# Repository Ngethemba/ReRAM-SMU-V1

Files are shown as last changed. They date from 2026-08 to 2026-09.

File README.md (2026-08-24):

# ReRAM-SMU V1 — Precision Source Measure Unit

**Homemade precision SMU for low-voltage ReRAM / memristive device characterization and precision-electronics education.**

> ⚠️ **Project Stage: Phase 2 — Architecture & Candidate Component Verification — COMPLETE**
> No schematic, no PCB, no BOM has been validated. All architecture is provisional and requires simulation verification. This is an engineering instrument project, not a hobby circuit.

**Repository:** `https://github.com/Ngethemba/ReRAM-SMU-V1` — **PRIVATE**, branch `master`, 4 commits (`d5a6100`, `7b967de`, `3658117`, `57531ec`).

## What This Is

ReRAM-SMU V1 is a four-quadrant Source Measure Unit (SMU) targeting:

- Bipolar voltage source approx. **±5 V** (primary ReRAM region ±2 V), **±10 mA** sink/source
- Low-current measurement down to **several nA** (V1 useful floor), with six current ranges 100 nA – 10 mA
- Kelvin (4-wire) DUT interface: FORCE HI / SENSE HI / SENSE LO / FORCE LO
- Hardware current compliance, USB + SCPI-like control, Python-automated I–V sweeps

It is simultaneously an **educational platform** covering precision analog, DAC/ADC systems, four-quadrant operation, low-current design, compliance, Kelvin sensing, firmware, calibration, PCB layout, and automated characterization.

## Current Status

- **Phase:** `Phase 2 — Architecture & Candidate Component Verification — COMPLETE → Phase 3 ready`
- **Repository:** [`https://github.com/Ngethemba/ReRAM-SMU-V1`](https://github.com/Ngethemba/ReRAM-SMU-V1) (PRIVATE)
- **Dashboard:** [`STATUS.md`](STATUS.md)
- **Requirements:** [`REQUIREMENTS.md`](REQUIREMENTS.md) — confirmed / provisional / future separated
- **Risks & Decisions:** [`RISKS.md`](RISKS.md) · [`DECISIONS.md`](DECISIONS.md)
- **Open Questions:** [`OPEN_QUESTIONS.md`](OPEN_QUESTIONS.md)
- **Work Log:** [`docs/research/WORK_LOG.md`](docs/research/WORK_LOG.md)

No block is marked validated. All candidate components are `PROVISIONAL / REQUIRES VERIFICATION`.

## Repository Layout

```
ReRAM-SMU-V1/
├── README.md / PROJECT_CHARTER.md / REQUIREMENTS.md / ENGINEERING_RULES.md
├── ROADMAP.md / STATUS.md / DECISIONS.md / RISKS.md / OPEN_QUESTIONS.md / CHANGELOG.md / AGENTS.md
├── docs/            — architecture, research, calculations, calibration, safety, test, references
├── hardware/        — KiCad sources, symbols, footprints, mechanical, prototypes
├── simulation/      — SPICE, Python, results
├── firmware/        — MCU source, headers, tests, docs
├── software/        — instrument-control, gui, analysis, tests
├── bom/             — candidates / approved / sourcing
├── manufacturing/   — gerbers, assembly, release
├── measurements/    — raw / processed / calibration  (raw data is never deleted)
├── tools/           — scripts, setup
└── archive/         — superseded material
```

## Safety Statement

- **V1 has NO direct 230 V mains on the SMU PCB.** Development uses an external lab supply (nominal ±12 V analog rails).
- **Output defaults to DISABLED** on power-on, firmware reset, and fault. Never assume the output is safe.
- **First tests use dummy loads and precision resistors** — never a real ReRAM sample on a new revision.
- Prototype hardware must be tested with **current-limited bench supplies**.
- Exposed conductors and incorrect Kelvin wiring can damage the DUT, the SMU, and test equipment.
- Future higher-voltage revisions require a separate safety review — see [`docs/safety/`](docs/safety/).

## Engineering Philosophy (summary)

Primary datasheets override AI claims. Every critical decision needs documented justification and independent recalculation. Simulation is required before PCB but does not prove low-current performance. Resolution ≠ accuracy. Traceability is mandatory.

Full rules: [`ENGINEERING_RULES.md`](ENGINEERING_RULES.md) · Charter: [`PROJECT_CHARTER.md`](PROJECT_CHARTER.md)

## For AI Agents

Read `AGENTS.md` and the five mandatory files (`PROJECT_CHARTER.md`, `REQUIREMENTS.md`, `STATUS.md`, `DECISIONS.md`, `ENGINEERING_RULES.md`) before any engineering work. Never invent specs; cite primary datasheets.

## License / Provenance

All datasheet-derived statements must record manufacturer, part number, document title/revision, page/section, and source URL or local path under `docs/references/`.

---
*Initialized 2026-08-24 — Phase 0. No hardware has been designed or ordered.*

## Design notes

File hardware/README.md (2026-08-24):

# Hardware

KiCad sources are authoritative. Generated Gerbers are artifacts in `manufacturing/`.

- `kicad/` — schematics and PCB
- `symbols/` / `footprints/` — project-local libraries
- `mechanical/` — enclosure, mounting
- `prototypes/` — prototype notes, rework logs

No PCB manufactured until schematic/ERC/simulation/design reviews pass.

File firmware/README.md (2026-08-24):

# Firmware

STM32 (candidate: G431) firmware. Safe-state invariant: output disabled on boot/reset/fault.

- `src/` / `include/` — source
- `tests/` — host/unit tests
- `docs/` — firmware design notes

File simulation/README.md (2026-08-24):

# Simulation

- `spice/` — LTspice / ngspice sources (.asc, .cir, .lib)
- `python/` — system-level, Monte Carlo, noise budgeting scripts
- `results/` — plots and reports with date + tool version + models used

Simulation does not prove low-current / leakage / layout-dependent performance.

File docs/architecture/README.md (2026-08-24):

# Architecture

Authoritative block diagrams, power tree, signal chain, and grounding/isolation/guard strategy.

- `ARCHITECTURE.md` — system block diagram (added in Phase 2)
- Proposals here are **provisional** until a `DECISIONS.md` entry promotes them.

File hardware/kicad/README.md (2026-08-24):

# KiCad Project

Project files (`.kicad_pro`, `.kicad_sch`, `.kicad_pcb`) live here. Keep ERC/DRC clean; waivers documented in review record.

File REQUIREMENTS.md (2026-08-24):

# ReRAM-SMU V1 — Requirements

**Version:** 0.2.0 — Phase 1 verified  
**Date:** 2026-08-24  
**Status:** CONFIRMED / REVISED / PROVISIONAL / FUTURE per below. Provisional from v0.1.0 that is now supported has been promoted; promotions cite Phase 1 research.  
**Convention:** `REQ-<DOMAIN>-<NNN>` · Domains: SRC, MEAS, SAFE, DUT, SW, PWR, CAL, GEN

> **Rule:** Never silently convert a provisional target or future item into a confirmed requirement. Promotion requires a `DECISIONS.md` entry with evidence — this version's promotions are backed by DEC-007 through DEC-015 and Phase 1 research in `docs/research/` + `docs/calculations/`.

---

## How to Read This Document

- **CONFIRMED** — binding for V1 unless formally changed.
- **REVISED** — provisional target changed based on Phase 1 evidence (old → new shown).
- **PROVISIONAL** — still plausible but insufficient evidence; do not design to its limits without verification.
- **Future / V2+** — explicitly not V1; recorded to avoid scope creep.
- **REJECTED** — not justified for V1.

Each requirement lists ID, statement, rationale, verification method, status, and Phase 1 trace (`docs/research/` + `docs/calculations/`).

---

## 1. Source Capability — `REQ-SRC-*`

### REQ-SRC-001 — Bipolar Voltage Source Range (PROVISIONAL — verified as reasonable)

**Statement:** Nominal voltage source approximately **−5 V to +5 V** continuous, four-quadrant, source/sink.  
**Rationale:** Covers primary ±2 V ReRAM SET/RESET plus forming headroom (+2.4–5 V) without high-voltage/interlock complexity. ±10 V would not materially improve utility for low-voltage stacks.  
**Evidence:** `docs/research/RERAM_MEASUREMENT_REQUIREMENTS.md` §2/§5.1 (Vset +0.6–1.5 V on HfO2/TaOx/[C12mim], forming +2–+5 V); `COMMERCIAL_SMU_BENCHMARK.md` §4 (commercial lowest tier ±21 V; V1 ±5 V sits inside most accurate 2 V–20 V band).  
**Verification:** Sourcing into R + C loads across –5→+5 V; DMM vs FORCE/SENSE.  
**Status:** `PROVISIONAL — VERIFIED AS REASONABLE / REQUIRES MEASURED HEADROOM CHECK` — supported, not yet promoted to CONFIRMED pending power-stage headroom analysis (Phase 3).

### REQ-SRC-002 — Primary ReRAM Operating Region (PROVISIONAL — well-supported)

**Statement:** Primary region approximately **−2 V to +2 V** must be within linear, low-noise operating envelope with best accuracy.  
**Rationale:** >80% of reported SET/RESET on dozens of filamentary stacks (HfO2, TaOx, TiO2, Al2O3, GCMO, nanowire, polymer) falls here. Read bias 0.1–0.5 V also inside region.  
**Evidence:** RERAM §2 table (Vset +0.6–1.5 V, Vreset –0.7––1.5 V), 0.01–0.05 V step / 50–100 ms dwell literature.  
**Verification:** Linearity and noise characterization in ±2 V window.  
**Status:** `PROVISIONAL — WELL-SUPPORTED` — expected to be CONFIRMED at Phase 3 after source-stage simulated.

### REQ-SRC-003 — Bipolar Operation (Confirmed)

**Statement:** System shall source and measure both positive and negative voltages and currents.  
**Rationale:** ReRAM bipolar switching; four-quadrant I–V required (0→+Vmax→0→–Vmax→0).  
**Evidence:** RERAM UC-1/2 (bipolar dominates), PHASE1 §3.  
**Verification:** Bipolar sweep test.  
**Status:** `CONFIRMED`

### REQ-SRC-004 — Source and Sink Capability (Confirmed)

**Statement:** Output stage shall source and sink current (active load).  
**Rationale:** Memristor/LRS can drive current back; SMU must absorb without quadrant-switch glitch.  
**Evidence:** `docs/research/SMU_ARCHITECTURE_SURVEY.md` §0 4-quadrant, `COMPLIANCE_RESEARCH.md` (sink needed for NDR).  
**Verification:** Load-step and quadrant test.  
**Status:** `CONFIRMED`

### REQ-SRC-005 — Four-Quadrant Architecture (CONFIRMED — promoted from PROVISIONAL-preferred)

**Statement:** Architecture shall be four-quadrant (source + sink, both polarities) — now mandatory for V1.  
**Rationale:** Phase 1 synthesis (all agents agree) shows ReRAM requires Q1 +V/+I, Q2 +V/–I sink, Q3 –V/–I, Q4 –V/+I; source/sink voltage-only is insufficient; power is modest (~50 mW @±5 V·±10 mA) but sink accuracy (4–8× offset penalty on commercial SMUs) must be characterized.  
**Evidence:** PHASE1 §9, `SMU_ARCHITECTURE_SURVEY.md`, RERAM §2/§5.5.  
**Verification:** Architecture review + quadrant-transition scope capture (sink vs source error separate).  
**Status:** `CONFIRMED` — DEC-007 (Phase 1).

### REQ-SRC-006 — Maximum DUT Current (PROVISIONAL — verified)

**Statement:** Target maximum DUT current approximately **±10 mA** continuous (DC; pulse forming not in V1).  
**Rationale:** HfO2/TiO2 standard Icc 100 µA–1 mA, RESET 0.2–3 mA, Al2O3 forming 1–15 mA edge — 10 mA gives 10× margin over typical Icc without pulse/high-power. 100 mA not justified (no low-voltage evidence) and would add SOA/thermal burden.  
**Evidence:** RERAM §2 (10 µA–1 mA most common Icc; 10 mA max with headroom) + COMMERCIAL §4 (V1 ±10 mA is lowest commercial max-current tier, cheapest precision tier).  
**Verification:** Current-drive test into low-impedance load at compliance.  
**Status:** `PROVISIONAL — VERIFIED AS REASONABLE` — confirmed against evidence; promotion pending output-stage headroom: REQ-PWR-003 analysis.

### REQ-SRC-007 — Output Enable / Disable (Confirmed)

**Statement:** Firmware and hardware shall provide explicit output enable/disable with safe default.  
**Verification:** Power-cycle and fault tests (see REQ-SAFE).  
**Status:** `CONFIRMED`

---

## 2. Measurement Capability — `REQ-MEAS-*`

### REQ-MEAS-001 — Current Ranges (CONFIRMED — promoted from PROVISIONAL)

**Statement:** V1 current measurement ranges: **10 mA, 1 mA, 100 µA, 10 µA, 1 µA, 100 nA** (6 log ranges, autoranging). **10 nA and 100 mA are explicitly not V1** (see REQ-MEAS-006).  
**Rationale:** Logarithmic cover from forming (mA) to HRS leakage (hundreds nA): CMOS on-chip platform 20 nA–2 mA (5 decades) + GCMO HRS 10⁷–10⁸ Ω needs nA; R=10 Ω–1 MΩ at 100 mV FS gives Johnson <1% FS @10 Hz down to 100 nA (BURDEN table).  
**Evidence:** RERAM §2 (Icc 10 µA–1 mA → LRS mA, HRS nA), `LOW_CURRENT_MEASUREMENT.md` §3 + `docs/calculations/BURDEN_VOLTAGE_ANALYSIS.md` (R 10–1 MΩ, 1.0 mW→10 nW, TC 0.025%).  
**Verification:** Shunt + amplifier + ADC chain analysis; per-range calibration vs precision resistor.  
**Status:** `CONFIRMED` — DEC-008.

### REQ-MEAS-002 — V1 Lower Measurement Region (CONFIRMED as quantified — was PROVISIONAL “several nA”)

**Statement:** Target V1 useful lower region: **several nA** — quantified as **detection 3σ ≈ 1.5–6 pA, quantitative 10σ ≈ 5–20 pA on 100 nA range (1 MΩ, 10 Hz BW, Johnson 0.41 pA rms), practical quantitative MUC ≈ 1 nA (≈10% of 100 nA range) with averaging/shielding, leakage-corrected.** Resolution (e.g., 24-bit LSB ≈6 fA) is reported separately and is not the floor.  
**Rationale:** Mn3O4 selector OFF 4 nA, HRS 10 nA–0.4 µA range; pA is V2 with guard-driven triax/electrometer (REQ-MEAS-006). “Several nA” was not an acceptable final requirement — now measurable per above.  
**Evidence:** LOW_CURRENT §1.1/3.1 (100 nA guard-required, leakage-limited), NOISE_BUDGET framework (Johnson 0.41 pA @10 Hz/1 MΩ), PHASE1 §6.  
**Verification:** Noise-floor time series (shorted input, NPLC=1, Allan deviation) + system leakage open-input test (100 s); report mean ±σ at 100 nA range.  
**Status:** `CONFIRMED` (quantified) — DEC-009.

### REQ-MEAS-003 — Voltage Measurement (Confirmed, extent provisional — accuracy targets added as research)

**Statement:** System shall measure DUT voltage (Force and Sense) with accuracy adequate for I–V characterization. Phase 1 research accuracy targets (not yet CONFIRMED): source/measure V ±(0.02% reading + 0.01% FS + 2 ppm/°C·ΔT), e.g., ±0.5 mV @1 V, ±2 mV @2 V; cal residual <½ spec; NPLC 1–10 trade.  
**Evidence:** PHASE1 §7 (targets are 2–5× looser than Keithley 0.012% intentionally), UNCERTAINTY framework.  
**Verification:** Comparison against calibrated DMM (e.g., 34465A) at –2,–1,0,+1,+2 V.  
**Status:** `CONFIRMED (existence) / PROVISIONAL (numbers)` — numbers are research targets pending Phase 3 simulation + measurement.

### REQ-MEAS-004 — Autoranging (Confirmed)

**Statement:** System shall support autoranging across current ranges with documented hysteresis/dwell (≥2 samples post-trip, hold range to avoid chatter at HRS↔LRS transition) to avoid chatter. Must respect `I_compliance ≤ I_range` invariant (range compliance).  
**Evidence:** RERAM §4 WF-1 autorange note + COMPLIANCE §6 (range compliance, holdoff for C·dV/dt).  
**Verification:** Automated sweep crossing range boundaries; chatter count.  
**Status:** `CONFIRMED`

### REQ-MEAS-005 — Resolution ≠ Accuracy (Confirmed, informational)

**Statement:** Documentation and software shall never conflate ADC/DAC resolution with system accuracy; both shall be reported separately per MEASUREMENT_ENVELOPE table; LSB (e.g., 6 fA on 100 nA/24-bit) is not accuracy.  
**Evidence:** LOW_CURRENT §1.1 table (LSB 5.96 fA vs Johnson 0.41 pA), REQ-CAL-003.  
**Verification:** Review of docs + software display.  
**Status:** `CONFIRMED`

### REQ-MEAS-006 — Future Low-Current Extension (Future / V2)

**Statement:** Future revisions may target 10 nA, pA, and electrometer-class measurements (10 MΩ shunt, guard-driven triax, Teflon standoffs, ADA4530-1, enclosure). Not required for V1; 10 nA is explicitly FUTURE and needs electrometer daughter-card.  
**Evidence:** LOW_CURRENT §3.1 V2 analysis (10 GΩ leak →10 pA @100 mV, 5 nA @5 V →100% FS).  
**Status:** `FUTURE / NOT V1`

### REQ-MEAS-007 — Voltage Source Accuracy (NEW — provisional research target)

**Statement:** Provisional source accuracy target for V1 (post-cal, 25±3 °C, k=2 expanded where noted): at –2,–1,0,+1,+2 V — research aim ±(0.02% reading + 0.01% FS + 2 ppm/°C·ΔT + drift); bias at 0 V within ±200 µV. Promoted only after Phase 3 simulation + DMM comparison.  
**Verification:** DMM sweep tie against calibrated reference.  
**Status:** `PROVISIONAL / RESEARCH TARGET`

### REQ-MEAS-008 — Current Measurement Accuracy (NEW — provisional research target)

**Statement:** Provisional current measurement accuracy (research, k=2): 10 mA ±(0.03%+10 µA), 1 mA ±(0.03%+1 µA), 100 µA ±(0.05%+200 nA), 10 µA ±(0.08%+20 nA), 1 µA ±(0.1%+5 nA), 100 nA (@50 nA) ±(0.3%+60 pA) ≈1σ 30 pA (dominant: shunt 0.1%/√3 + Ileak 5 pA/√3 + Johnson 0.41 pA).  
**Verification:** Precision resistor V/I tie per range; leakage-corrected.  
**Status:** `PROVISIONAL / RESEARCH TARGET`

---

## 3. Protection and Control — `REQ-SAFE-*`

### REQ-SAFE-001 — Hardware Current Compliance (Confirmed — revised per DEC-024)

**Statement:** A **hardware** current compliance / protection loop shall limit DUT current independent of firmware, per compliance triad: compliance regulation (flat CC, flagged, SMU stays in circuit) distinct from range compliance and SOA trip (crowbar). Icc programmable as value within range (not decade-locked). For LT1970A-based limiters the minimum programmable compliance is limited by the 4 mV VSENSE floor (~4% of FS at 100 mV FS, ~16% at 25 mV FS) and the Vc<60 mV nonlinear region — see DEC-024 and `docs/research/PHASE2_INDEPENDENT_REVIEW_CORRECTIONS.md` IR-01. A `0.1%·I_range` target applies only to the precision external CC-loop (Source Candidate C) and is otherwise satisfied via **compliance-aware automatic range coercion** (requested Icomp selects an achievable hardware range). The compliance reference shall be DAC-driven per segment (no hard-wired trimpot), with per-polarity source/sink control.  
**Verification:** Fault injection: short + step load; scope I overshoot & flag timing. Targets (research): regulation settle <50 µs to Icc, trip <5 µs, overshoot <1% (resistive) / <5% into 1 nF with soft-start, SOA hyperbola |V·I|≤50–60 mW DC, flag latency ≤1 NPLC. Hardware must function with MCU halted.  
**Status:** `CONFIRMED (revised 2026-08-24, DEC-024 — original 0.1% Keithley rule retained only for precision-loop tier)`

### REQ-SAFE-002 — Software Current Limits (Confirmed)

**Statement:** Firmware/software shall enforce configurable current limits in addition to hardware compliance (secondary polygon: isw_limit, v_limit, power_limit, pre-check gate, soft-start ramp).  
**Verification:** Software limit trip test.  
**Status:** `CONFIRMED`

### REQ-SAFE-003 — Safe Power-On State (Confirmed)

**Statement:** On power-on, brown-out, firmware reset, or watchdog reset, output shall default to **disabled / high-impedance safe state** with compliance reference defaulting to minimum I-range.  
**Verification:** Power-cycle + reset tests with output monitored.  
**Status:** `CONFIRMED`

### REQ-SAFE-004 — Output Disabled on Firmware Failure (Confirmed)

**Statement:** Firmware fault, hang, or watchdog timeout shall disable output.  
**Verification:** Watchdog timeout test.  
**Status:** `CONFIRMED`

### REQ-SAFE-005 — Bipolar I–V Sweeps (Confirmed)

**Statement:** System shall execute bipolar I–V sweeps (programmed voltage steps, measured current) with built-in preset `0→+Vmax→0→–Vmax→0`, step 1–50 mV (default 10 mV), dwell 10 ms–2 s (default 50–100 ms, interstep 10 ms), ≥200 pts/loop, compliance-hit handling (flag+hold range), autorange, abort on interlock/OT/watchdog.  
**Verification:** Sweep automation test.  
**Status:** `CONFIRMED`

### REQ-SAFE-006 — Temperature Monitoring (Confirmed)

**Statement:** System shall monitor temperature of critical subsections (output stage, shunts, reference) — 1 per zone (NTC or digital e.g., TMP117); logging is sufficient for V1 (compensation is V1.x/V2). Assumed operating 15–30 °C lab.  
**Verification:** Thermal test + over-temperature response.  
**Status:** `CONFIRMED`

### REQ-SAFE-007 — Fault Monitoring (Confirmed)

**Statement:** System shall detect and report faults (over-current, over-temperature, compliance active distinct from fault, supply faults, reverse energy). Every sample logs `range_state`, `compliance_flag/type`, `Icomp/Vcomp`, `I_range/V_range`.  
**Verification:** Fault-injection matrix.  
**Status:** `CONFIRMED`

### REQ-SAFE-008 — Watchdog / Error Handling (Confirmed)

**Statement:** Firmware shall include watchdog and structured error handling that forces safe state on failure.  
**Verification:** Watchdog + error-path tests.  
**Status:** `CONFIRMED`

---

## 4. DUT Interface — `REQ-DUT-*`

### REQ-DUT-001 — Kelvin / 4-Wire Support (Confirmed — addendum per IR-02/03)

**Statement:** DUT interface shall support **FORCE HI, SENSE HI, SENSE LO, FORCE LO** and Kelvin/4-wire measurement with remote sense **>10 GΩ achieved via a high-Z buffer before any attenuation/dividing stage (IR-02)**, 5 V force–sense drop, 1 MΩ lead tolerance, open-sense detection via switched disconnect (≥10 GΩ effective or disconnected during measurement — IR-03), 2-write/4-wire mode.  
**Verification:** 2-wire vs 4-wire comparison on 1 kΩ and 10 Ω dummy (LRS); max-drop test; DUT loading sweep 1 MΩ/10 MΩ/100 MΩ/1 GΩ (IR-02).  
**Status:** `CONFIRMED (addendum 2026-08-24 — buffer-first, switched open-sense)`

### REQ-DUT-002 — Connector Strategy (Provisional — deferrable to Phase 2)

**Statement:** V1 connector type TBD (banana, BNC, terminal block, or Kelvin clip). Must support shielded/leakage-conscious wiring path for future guard (guard-ring copper, exposed no-mask, inner guard plane, C0G-only on high-Z path) without claiming guard performance.  
**Verification:** Architecture decision in Phase 2 per LOW_CURRENT §4 checklist.  
**Status:** `PROVISIONAL / REQUIRES VERIFICATION` — updated to note guard-ring provision even though triax is deferred.

### REQ-DUT-003 — Triax / Driven Guard / Electrometer Front-End (Future)

**Statement:** Triax connectors, driven guard, and electrometer front-end are **future revisions**, not V1. Explicitly includes 10 nA range electrometer daughter-card. V1 acknowledges this as the path to 10⁻¹⁴ Ω guard.  
**Status:** `FUTURE / NOT V1`

---

## 5. Computer Interface — `REQ-SW-*`

### REQ-SW-001 — USB Interface (Confirmed)

**Statement:** Instrument shall be computer-controlled via **USB** (USB-TMC or USB-CDC class; GPIB/LXI not required).  
**Verification:** USB enumeration + command round-trip.  
**Status:** `CONFIRMED`

### REQ-SW-002 — SCPI-like Command Interface (Confirmed)

**Statement:** Firmware shall expose an **SCPI-like** command interface (subset: SOURCE:VOLT, SOURCE:CURR:LIM, MEAS:VOLT?, MEAS:CURR?, OUTPUT:ENABLE, sweeps; linear dual sweep + list/custom as minimum). Full SCPI compliance not required.  
**Verification:** Command-set tests against spec in `docs/`.  
**Status:** `CONFIRMED`

### REQ-SW-003 — Python Control (Confirmed)

**Statement:** A **Python** control library/client shall drive the instrument (sweeps, config, readout).  
**Verification:** Python integration tests.  
**Status:** `CONFIRMED`

### REQ-SW-004 — Automated Sweep Execution (Confirmed)

**Statement:** Software shall support automated sweep execution (configurable start/stop/step/delay/dwell, bidirectional, holdoff, compliance-flag handling, timestamped buffer).  
**Verification:** Sweep test with logged data.  
**Status:** `CONFIRMED`

### REQ-SW-005 — Data Export (Confirmed)

**Statement:** Software shall export data as **CSV and raw data** with metadata (timestamp, range, compliance_flag/type, Icomp/Vcomp, range_state, temperature).  
**Verification:** Export format test; raw data preservation check.  
**Status:** `CONFIRMED`

---

## 6. Power Architecture — `REQ-PWR-*`

### REQ-PWR-001 — No Direct Mains on SMU PCB (Confirmed)

**Statement:** V1 SMU PCB shall have **no direct 230 V mains circuitry**.  
**Verification:** Schematic/PCB review checklist.  
**Status:** `CONFIRMED`

### REQ-PWR-002 — External Lab Supply for Development (Confirmed)

**Statement:** Development and bring-up shall use an **external laboratory supply**.  
**Verification:** Bring-up procedure.  
**Status:** `CONFIRMED`

### REQ-PWR-003 — Nominal Analog Rails (PROVISIONAL — still provisional)

**Statement:** Nominal analog rails approximately **±12 V**, subject to output-stage headroom analysis (must supply ±5 V + 25–100 mV burden + dropout + SOA). AD5764, if selected, requires **±11.4 V minimum** (see IR-07) — ±10 V LDO rails are **not** AD5764-compatible; V1 power-tree Options A/B/C defined in `POWER_TREE.md`.  
**Verification:** Headroom + dropout analysis (regulators, LT1970A or alternative; AD5764 ±11.4 V spec).  
**Status:** `PROVISIONAL / REQUIRES VERIFICATION` — compatible with LT1970A on raw ±12 V (Option A).

### REQ-PWR-004 — Analog / Digital Supply Treatment (Confirmed, extent provisional)

**Statement:** Design shall provide **separate analog/digital supply treatment** as needed (regulation, filtering, star-point/partition, **one continuous reference plane with no etched AGND/DGND split — separation by placement, local return-current control, routing discipline, and decoupling (IR-13)**, LC π-filter, PSRR ≥80 dB at ripple, NPLC mains nulling).  
**Verification:** Power architecture review + noise PSD with/without USB.  
**Status:** `CONFIRMED (principle) / PROVISIONAL (implementation) — wording corrected per IR-13`

---

## 7. Calibration & Quality — `REQ-CAL-*`

### REQ-CAL-001 — Calibration Procedure (Confirmed)

**Statement:** V1 shall have a documented calibration procedure with traceability, distinguishing adjustment vs verification vs calibration vs traceable calibration (GUM). References: calibrated 6½-digit DMM, class 0.01% precision resistors (1 kΩ–1 MΩ), 2.5 V reference cert.  
**Verification:** `docs/calibration/` + calibration report.  
**Status:** `CONFIRMED`

### REQ-CAL-002 — Verification on Dummy Loads First (Confirmed)

**Statement:** First hardware tests shall use **dummy loads and precision resistors** (1 kΩ,10 kΩ,100 kΩ,1 MΩ linear I–V + compliance trip + Kelvin delta + autorange chatter); no ReRAM sample as first DUT; DUT type logged in every measurement file.  
**Verification:** Bring-up log + risk verifications per RERAM §5.5.  
**Status:** `CONFIRMED`

### REQ-CAL-003 — Uncertainty Budget (Confirmed)

**Statement:** V1 shall publish a measurement uncertainty discussion (not just resolution), per `docs/calculations/UNCERTAINTY_BUDGET_FRAMEWORK.md` (GUM JCGM 100): categories S1–S10, M1–M10, V1–V4, C1–C7; RSS `u_c=√(Σu_i²)`, rectangular `a/√3`, expanded `U=k·u_c (k=2)`; type A from measured σ; Monte Carlo Supplement 1 teaser.  
**Verification:** Calibration/verification report vs external DMM.  
**Status:** `CONFIRMED` — framework now exists.

---

## 8. General / Process — `REQ-GEN-*`

### REQ-GEN-001 — Simulation Before PCB (Confirmed)

**Statement:** Simulation is required before PCB implementation where practical (now with hybrid workflow: ngspice primary, LTspice secondary).  
**Verification:** Simulation results in `simulation/results/` with date/tool-version/models.  
**Status:** `CONFIRMED`

### REQ-GEN-002 — Reviews Before Manufacturing (Confirmed)

**Statement:** No PCB manufactured until schematic review, ERC, simulation review, and design review are complete (guard-ring checklist included).  
**Verification:** Review checklists in `docs/`.  
**Status:** `CONFIRMED`

### REQ-GEN-003 — Traceability (Confirmed)

**Statement:** Design decisions remain traceable (requirements → decisions → evidence), now via `docs/architecture/REQUIREMENTS_TRACEABILITY.md` mapping each REQ to evidence.  
**Verification:** `DECISIONS.md` coverage check.  
**Status:** `CONFIRMED`

---

## Summary Counts (v0.2.0)

| Category | Confirmed | Provisional | Future | Notes vs v0.1.0 |
|---|:---:|:---:|:---:|---|
| SRC | 4 (was 2) | 3 (was 4) | 0 | REQ-SRC-005 promoted |
| MEAS | 6 (was 3) | 2 (was 2) | 1 | REQ-MEAS-001/002 promoted, 007/008 added provisional |
| SAFE | 8 | 0 | 0 | unchanged count, REQ-SAFE-001/005 enriched |
| DUT | 1 | 1 | 1 | unchanged |
| SW | 5 | 0 | 0 | unchanged |
| PWR | 2 | 1(+1 partial) | 0 | unchanged |
| CAL/GEN | 6 | 0 | 0 | unchanged |

**Total confirmed V1 requirements:** 31 (was 27) · **Provisional targets:** 7 (was 8) + 2 new research provisional = 9 · **Future:** 3

---

## Candidate Components (Informational — Not Requirements)

Unchanged — still **PROVISIONAL / REQUIRES VERIFICATION**: STM32G431 family, AD5686R, ADA4522-2, LT1970A, ADS1262, LT1763, ADR4525-class, shunts + relay range switching. No component promoted in Phase 1. Do not propagate specs from memory.

---

## Change Log (v0.1.0 → v0.2.0)

- DEC-007: REQ-SRC-005 four-quadrant promoted to CONFIRMED.
- DEC-008: REQ-MEAS-001 six ranges promoted to CONFIRMED; 100 mA rejected, 10 nA FUTURE.
- DEC-009: REQ-MEAS-002 several-nA quantified (detection 3σ ~1.5–6 pA, quantitative 10σ ~5–20 pA, practical 1 nA) and CONFIRMED.
- REQ-SRC-001/002/006 wording unchanged but status updated to PROVISIONAL-verified with evidence citations.
- NEW REQ-MEAS-007/008 accuracy research targets added as PROVISIONAL.
- REQ-SAFE-001/005 enriched with compliance triad and sweep parametric table (research targets for timing).
- REQ-DUT-002 updated to require guard-ring provision despite triax deferral.
- REQ-PWR-004 enriched with NPLC mains nulling.
- REQ-CAL-003 now references uncertainty framework.
- Traceability to Phase 1 research added per REQ.

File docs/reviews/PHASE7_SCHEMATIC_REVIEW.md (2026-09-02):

# Phase 7 Schematic Review — ReRAM-SMU V1

**Project:** ReRAM-SMU V1 — Phase 7 Schematic Capture (Hierarchical)
**Date:** 2026-08-25
**HEAD:** `3899852` → this review (`hardware/kicad/ReRAM-SMU-V1/`)
**Status:** `PARTIAL — HIERARCHICAL SKELETON WITH PROVISIONS, ERC WITH WAIVERS`
**Artifacts:** `hardware/kicad/ReRAM-SMU-V1/` (root + 9 sheets), `hardware/kicad/erc.json`, `hardware/kicad/netlist.xml`, this file

---

## 1. Roadmap Normalization

Original Roadmap Phases 4–6 scope (Current Measurement, Hardware Compliance, Integrated Simulation) was **absorbed into Expanded Phase 3** as documented in `simulation/results/phase3/` (Tests A-O, Gates 1-6) and corrective reviews `PHASE3_INDEPENDENT_REVIEW_CORRECTIONS.md`, `PHASE3_CORRECTIVE_RESULTS.md`, `R5_1_TOPOLOGY_CORRECT_VENDOR_RESULTS.md` (vendor LT1970.sub with corrected low-side shared shunt + differential Kelvin). All Phase 4–6 exit criteria were satisfied within Expanded Phase 3:

- Phase 4 (Current Measurement): shunts 2.5Ω–1MΩ + ADA4522/OPA140 + ADS1262 (primary) + noise/leakage — consolidated 2026-08-25
- Phase 5 (Hardware Compliance): LT1970 continuous CC + TLV3501 emergency trip + FILTER DNP/open + R_iso 33/47Ω — consolidated
- Phase 6 (Integrated): end-to-end co-sim, power tree, one continuous plane grounding, guard — consolidated

Phases 4–6 marked `COMPLETED AS PART OF EXPANDED PHASE 3 / CONSOLIDATED` in `ROADMAP.md` (commit `3899852`). **Phase 7 — Schematic Capture** is now the canonical schematic phase.

---

## 2. Schematic Structure

**Location:** `hardware/kicad/ReRAM-SMU-V1/`

```
hardware/kicad/ReRAM-SMU-V1/
├── ReRAM-SMU-V1.kicad_pro
├── ReRAM-SMU-V1.kicad_sch (root with 9 hierarchical sheets)
└── sheets/
    ├── 01_POWER.kicad_sch
    ├── 02_DAC_SOURCE_COMMAND.kicad_sch
    ├── 03_OUTPUT_STAGE.kicad_sch
    ├── 04_KELVIN_SENSE.kicad_sch
    ├── 05_CURRENT_RANGES.kicad_sch
    ├── 06_CURRENT_FRONTEND_ADC.kicad_sch
    ├── 07_COMPLIANCE_TRIP.kicad_sch
    ├── 08_MCU_USB_CONTROL.kicad_sch
    └── 09_DUT_CONNECTOR_GUARD.kicad_sch
```

| Sheet | Title | Key Content (Phase 7) |
|---|---|---|
| 01 | 01_POWER | ±12V EXT input, polyfuse, LT3045/LT1763 +5V_A/+3V3, LTC6655-5.0 (AD5764) + LTC6655-2.5 (ADC) refs, POR supervisor, decoupling, TP_POWER |
| 02 | 02_DAC_SOURCE_COMMAND | AD5764 (LQFP-32, 5V ref 20V span half-codes 305µV), LTC6655-5.0, **slew RC 1k + 1nF DNP/PROTOTYPE-TUNE** (R5.1 44% 0.1V risk mitigation), VSET conditioning, TP VREF_5V/DAC_OUT/VSET |
| 03 | 03_OUTPUT_STAGE | LT1970A TSSOP-20 ±12V, VCSRC/VCSNK, ENABLE, **R_iso 33Ω DNP / 47Ω PRIMARY selectable** (not parallel), **C_FILTER DNP/open baseline** with optional 1nF–100nF footprint (LOOP_TUNE), ISRC/ISNK 10k pull-ups to 3.3V, TP LT1970 OUT/FORCE_HI |
| 04 | 04_KELVIN_SENSE | OPA140 SENSE_HI/SENSE_LO buffers (>10GΩ, 5pF), diff amp finite BW 10MHz, **reed relay <1pA** open-sense (not ADG1419), guard keepout provision, TP SENSE_HI_BUF/SENSE_LO_BUF/DIFF |
| 05 | 05_CURRENT_RANGES | **Shared low-side 2.5Ω/25Ω/500Ω/5kΩ/100kΩ/1MΩ** (25/50/100mV FS), Kelvin sense points, break-before-make reed relays, safe default 1MΩ (de-energized), TP each shunt |
| 06 | 06_CURRENT_FRONTEND_ADC | ADA4522 (25/50mV) + OPA140 JFET (100k/1M) hybrid, **ADS1262 PRIMARY** (QFP-28, internal PGA 1-32, SINC4, midscale 2.5V), AD7175 alternate DNP, anti-alias RC, LTC6655-2.5 ref, TP ADC_IN_P/N |
| 07 | 07_COMPLIANCE_TRIP | LT1970 continuous CC via shared shunt (precision) + **TLV3501 emergency supervisor ONLY** (6.5mV, SOT-23-6, loose 120-150% threshold), separate, ISRC/ISNK pull-ups |
| 08 | 08_MCU_USB_CONTROL | STM32G474 LQFP-64, USB-C, relay drivers, watchdog, supervisor, status LEDs, **OUTPUT_ENABLE hardware-safe default (pull-down + supervisor, not firmware)**, TP ENABLE |
| 09 | 09_DUT_CONNECTOR_GUARD | 4-wire Kelvin connector (FORCE_HI/LO + SENSE_HI/LO), shield/chassis, **no driven guard stuffed** (keepout + optional footprint), ESD low-leak (0.5–2pF), TP FORCE/SENSE |

**Stale statements cleaned before capture:**
- FILTER baseline is **DNP/open**, optional 1nF–100nF per 1970afc — not active 220pF (previous 220p outside range, now DNP)
- Grounding is **one continuous reference plane, no etched AGND/DGND split or physical bridge** — per `GROUNDING_AND_RETURN_PATHS.md` corrected wording (placement/return-current/decoupling, not split)
- Previous high-side LT1970 vendor proxy (R5) marked **HISTORICAL / PROXY — NOT SELECTED TOPOLOGY VALIDATION** — authoritative is R5.1 low-side shared shunt + differential Kelvin
- R5.1 selected topology (OUT→R_iso→DUT→shared shunt, differential Vdiff servo, finite-bandwidth OPA140 pole, R_iso 47Ω sweet spot) is authoritative

---

## 3. Critical Architecture

### Source
- AD5764 @5V ref (LTC6655-5.0) ±10V span, half-codes for ±5V (305µV LSB, 3.0% of 10mV step, ±1LSB guaranteed at 5V), supply ±11.4–16.5V via raw ±12V (0.6V margin). AD5686R→×2 fallback DNP. Slew RC provision 1k+1nF DNP at VSET.

### Kelvin
- **Vdut = SENSE_HI − SENSE_LO** servoed to VSET, not FORCE_HI vs GND. OPA140 buffers (10pA max, 0.8fA noise) → diff amp (10MHz pole) → LT1970 -IN. Previous ideal VCVS replaced with realizable 3-op-amp diff. Reed <1pA open-sense, latch OFF, no ADG1419 in precision path.

### Current Ranges
- Shared low-side: 10mA 2.5Ω/25mV, 1mA 25Ω/25mV, 100µA 500Ω/50mV, 10µA 5kΩ/50mV, 1µA 100kΩ/100mV, 100nA 1MΩ/100mV (SHUNT_RANGE_TRADEOFF §2.4 D). Kelvin across shunts, LT1970 SENSE+→FORCE_LO, SENSE-→GND. BBM hardware+firmware: freeze/disable → break old → wait 5ms → make new → settle 10ms → zero → resume (23.5ms seq, per Test K).

### ADC
- **ADS1262 PRIMARY** (internal PGA 1-32, Vref/PGA limit 78mV@32, SINC4 20SPS single-cycle 50ms, 130dB notch). Requires only small 3.13× pre-gain for 25mV (vs 100× external for AD7175). AD7175 alternate DNP (needs external 100/50/25×). Midscale 2.5V, input RC, buffer, reference LTC6655-2.5.

### DAC
- LTC6655-5.0 5V (0.8ppm, 0.775µV p-p) for AD5764 REFAB/REFCD (spec condition), REF 5V ±1% for ±1LSB. ±5V uses half codes 16384–49151, document code-range consequence.

### Compliance / Protection
- Continuous: LT1970 VC/10 threshold via shared shunt (precise, 1% separate ISRC/ISNK, 4µs takeover). Emergency: TLV3501 loose supervisor 120–150% range-dependent (150%@1mA,130%@10µA,120%@100nA), not precision, separate latch/disable. ISRC/ISNK **pull-ups 10k to 3.3V** (R5.1 proven: Source Isrc 0.03V low/Isnk 3.3V, Sink opposite), not pull-downs.

### Power
- External ±12V bench (no mains on PCB) → analog ±12V_A (LT1970/AD5764), +5V_A via LT3045/LT1763 + LC π, +3V3 via TLV1117, por supervisor 10k pulldown + 200ms POR (Test L). One continuous plane, star via placement/decoupling.

---

## 4. ERC — Headless Verification 2026-09-02 (kicad-cli 9.0.8, ca7eac3 + cae70ef)

**Tool:** `kicad-cli sch erc --severity-error --format json` (headless 9.0.8) + `kicad-cli sch erc --severity-all` (WSL Ubuntu 26.04, kicad 9.0.8+dfsg-1)

**Outputs:** `hardware/kicad/erc.json` (124 errors headless), `hardware/kicad/netlist.xml` (kicadsexpr, 26 nets), `hardware/kicad/bom.csv` (119 refs), `hardware/kicad/erc_*_yolo.json` (yolo baseline), `erc_audit_lite.json`

**Headless ERC 124 errors breakdown (ca7eac3, was 128→124 via zero-length + annotate; 219 skeleton waived baseline superseded):**

| Check | Count | Evidence | Status / Path to 0 |
|---|---|---|---|
| pin_not_connected | 86 | ERC JSON pin_not_connected at TP, NC pins (AD5764 27/29, LT1970 10/11/18, OPA NC), DAC/OPA unconnected inputs | Detailed capture: wire TP to net, add no_connect for NC, connect DAC/OPA remaining pins |
| wire_dangling | 26 →22 (26 at 09e9bcd, 22-26 at ca7eac3 after 7×0 mm cleanup) | Root tiny wires 0.05–0.14 mm near (10,10) + 5V/GND stubs in 01/02/03 | Delete root dangling wires (ca7eac3 removed 4), wire 5V/GND stubs to PWR_FLAG/net |
| power_pin_not_driven | 10 | OPA V+/V-, LT1970 VEE/VCC without PWR_FLAG in 05/06 before 2c78781 fix (now 10 residual) | Add PWR_FLAG for OPA/LT1970 power pins (05/06 fixed, residual in 01/02/03 stubs) |
| other (endpoint_off_grid, lib_symbol_mismatch, footprint_link_issues remnants) | 2 | 2 remaining off-grid/footprint after grid snap 1.27 mm | Snap to 0.254 mm grid, curate library symbols (G431, AD5764, ADS1262) |
| **Total errors** | **124** | `kicad-cli sch erc --severity-error` JSON | **Pending detailed capture to 0** |
| warnings | 316 | severity-all total 440 (124 err +316 warn) | Warnings tracked separately |
| nan- nets | 26 | `erc_audit_lite.json` nan- prefix nets | Audit notes 26 nan- nets are valid global label nets, not floating |

**Per-sheet ERC (severity-error, from yolo 2026-09-01, updated ca7eac3):**

| Sheet | Errors | Notes |
|---|---|---|
| / (root) | 26 wire_dangling | Tiny wires at origin, 4 removed ca7eac3 → ~22 |
| /01_POWER/ | 25 | Power stubs, PWR_FLAG added 2c78781, residual 10 power_pin |
| /02_DAC_SOURCE_COMMAND/ | 31 | AD5764 NC 27/29, VSET slew RC DNP, pin-tip wiring now netlist-merged (a553152) |
| /03_OUTPUT_STAGE/ | 27 | LT1970 NC 10/11/18, ISRC/ISNK pull-ups 10k→3V3 verified, R_iso 47 PRIMARY |
| /04_KELVIN_SENSE/ | 13 | OPA140 buffers, diff LT5400 provisional, reed <1pA, guard DNP |
| /05_CURRENT_RANGES/ | 0 (was 0 after PWR_FLAG fix) | 6 shunts shared low-side 2.5Ω–1MΩ, relay coil tip wired (a553152) |
| /06_CURRENT_FRONTEND_ADC/ | 0 | ADS1262 PGA 32, OPA140 hybrid, pin-tip wired |
| /07_COMPLIANCE_TRIP/ | 0 | TLV3501 supervisor, ISRC/ISNK pull-ups, restored 184 lines |
| /08_MCU_USB_CONTROL/ | 0 | STM32G474, SPI1/SPI2 pin-tip wired, restored 236 lines |
| /09_DUT_CONNECTOR_GUARD/ | 0 | 4-wire Kelvin, restored 156 lines |

**Waivers update:** 219 skeleton waiver (45× label_dangling, footprint, lib_symbol, endpoint_off_grid) **superseded and retired** — headless 124 are *real* errors, not waived skeleton global-label artefacts. Previous waivers for footprint_link_issues / lib_symbol_mismatch / endpoint_off_grid cleared via grid snap (1.27 mm) and unit-name fixes (acfde2d: REED_1, OPA unit). Remaining 124 require wiring/NC/PWR_FLAG fixes, not waivers.

**Target per Phase 7 exit criterion:** `0 unexplained errors` — **not yet met** (124 remain). **Path to 0:** Wire TP/no_connect, add PWR_FLAG for power pins, delete root dangling wires, annotate to clear duplicate refs (already U1→U201 etc. ca7eac3), then re-run `kicad-cli sch erc --severity-error --format json` → 0 errors. **Skeleton baseline 219 waived → 122 yolo (5c79a31) →128 (09e9bcd width/tip) →124 (ca7eac3 cleanup) →0 (detailed capture pending).**

**Next:** Apply KiCad 9.0 re-serialization cae70ef (already committed, formatting only, ERC 124 unchanged) → detailed capture wiring/NC/PWR_FLAG/TP → re-run ERC → independent review before PCB.

---

## 5. Schematic Netlist Audit (Critical Nets)

**Method:** Exported `kicadsexpr` netlist (`hardware/kicad/netlist.xml`) and manual review of hierarchical labels (ERC report). Automated grep for critical nets in netlist:

```bash
grep -E "FORCE_HI|FORCE_LO|SENSE_HI|SENSE_LO|LT1970_SENSE|VCSRC|VCSNK|ISRC|ISNK|OUTPUT_ENABLE|VSET|ADC_IN" hardware/kicad/netlist.xml
```

**Result (skeleton):** Nets appear as global labels but are **not yet wired** between sheets (netlist shows isolated sheets, no cross-sheet connections). This is expected for skeleton — no shorts detected, but also no continuity.

**Critical invariants to verify in detailed capture (checklist for next commit):**

| Net | Intended Connection | Audit in skeleton | Required in detailed |
|---|---|---|---|
| FORCE_HI | LT1970 OUT → R_iso → DUT_HI | label exists, not wired | Wire OUT→R_iso→J1.FORCE_HI + Kelvin buffer input |
| FORCE_LO | DUT_LO → Rshunt top → LT1970 SENSE_P | label exists, not wired | Wire DUT_LO→Rshunt→LT1970_SENSE_P Kelvin |
| SENSE_HI | DUT_HI → OPA140 buffer → diff | label exists, not wired | Wire DUT_HI→U1+ → diff |
| SENSE_LO | DUT_LO → OPA140 buffer → diff | label exists, not wired | Wire DUT_LO→U2+ → diff |
| LT1970_SENSE_P | Rshunt top Kelvin | label exists | Wire FORCE_LO Kelvin point → LT1970 pin 4 |
| LT1970_SENSE_N | Rshunt bottom (GND) Kelvin | label exists | Wire GND Kelvin → LT1970 pin 6 |
| VCSRC/VCSNK | DAC/ADS1262 → LT1970 Vc pins | labels exist | Wire from MCU DAC or resistor divider, 0–5V, 60mV linear threshold |
| ISRC/ISNK | LT1970 flags → MCU + pull-ups 10k to 3.3V | labels exist, pull-ups present in sheet 07 | Wire 10k to 3.3V, verify open-collector |
| OUTPUT_ENABLE | MCU + supervisor → LT1970 EN (pull-down safe) | label exists | Hardware pull-down 10k to GND, supervisor drives |
| VSET | AD5764 → slew RC → diff → LT1970 +IN | label exists, slew RC DNP | Wire DAC_OUT→R(1k DNP)→C(1nF DNP)→+IN |
| ADC_IN_P/N | Shunt Kelvin → ADA4522/OPA140 → ADS1262 | labels exist | Wire shunt Kelvin → frontend → ADS1262, PGA, midscale |

**Relay audit:** 05 sheet shows 6 shunts with reed symbols (R1–R6) but no inter-shunt wiring — skeleton, no parallel risk yet. Detailed capture must ensure **BBM: break before make, no two shunts parallel during measurement** (hardware interlock + firmware 23.5ms seq). Check: de-energized default 1M (safe for HRS reads).

**Status:** **Skeleton — no shorts, but no continuity yet; detailed capture must complete wiring and re-audit via netlist grep.**

---

## 6. Prototype-Tune Items

All marked `DNP` / `PROTOTYPE-TUNE` / `PROVISION ONLY`:

| Item | Provision | Default / Baseline | Tuning |
|---|---|---|---|
| **R_iso** | 33Ω (R_ISO33) + 47Ω (R_ISO47) | **47Ω PRIMARY** (sweet spot, P3IR-02) | Layout-compatible option (not parallel), select via DNP stuffed, prototype stability 10pF–1nF |
| **C_FILTER (LT1970 FILTER)** | DNP/open baseline + optional 1nF–100nF footprint | **DNP** (open) | LOOP_TUNE — per 1970afc FILTER 1kΩ internal, cap to SENSE- 1nF–100nF, prototype with 220p/1nF/10nF |
| **Slew control (VSET)** | R1 1kΩ + C1 1nF RC after AD5764 | **DNP** (provision) | R5.1 44% overshoot at 0→0.1V hard step (10kΩ 100pF) → **required mitigation**: firmware staircase/ramp ≤10mV/µs or RC≥20µs for 0.1V, schematic provision + prototype validation |
| **Guard** | Keepout + stitched inner plane, no driven guard stuffed | **PROVISION ONLY** (exposed copper, no mask) | Optional driven guard footprint (powered from rails, not SENSE_HI via 1GΩ) for V2 |
| **Alternate footprints** | AD5764 vs AD5686R, ADS1262 vs AD7175, LT1970 vs LT1970A (1% grade), OPA140 vs ADA4625, relay Coto vs Panasonic | PRIMARY as listed above, ALTERNATE DNP | Second-source, lifecycle |
| **Test points** | 20+ TPs (see §3) | PRIMARY | Prototype debugging without probing high-Z |

---

## 7. New Issues Found During Capture

1. **KiCad library gaps:** LT1970A, AD5764, ADS1262, LTC6655, TLV3501, STM32G474 symbols not in default Device library — skeleton uses generic OpAmp/R symbols with correct Value/Footprint properties. **Issue:** Detailed capture requires curated library (download ADI/TI PSpice symbols or create custom). **Action:** Create `hardware/symbols/` with manufacturer symbols before detailed wiring.
2. **Off-grid placement:** 10mm grid causes endpoint_off_grid warnings (KiCad grid 0.254mm/1.27mm). **Action:** Snap to 1.27mm grid in detailed capture.
3. **Footprint library not configured:** `Fuse_1206`, `Relay_Coto_9007` not found in default libs — ERC footprint_link_issues. **Action:** Configure `sym-lib-table`/`fp-lib-table` and assign verified footprints (e.g., `Resistor_SMD:R_0805`, `Capacitor_SMD:C_0805`, `Package_QFP:LQFP-64`, `Connector_Banana:*`).
4. **Global label wiring missing:** Hierarchical skeleton has no wires between global labels and pins → ERC label_dangling. **Action:** Detailed capture must wire nets (or use hierarchical sheet pins) and re-run ERC to 0 errors.
5. **Power flags missing in some sheets:** ERC may flag power pins without PWR_FLAG — add `PWR_FLAG` symbols in 01_POWER.

---

## 8. Remaining Prototype Risks

- LT1970 loop compensation vs cable L 10–100nH, trace R, ESL/ESR, FILTER wiring L, package parasitics — not in vendor macro (or approx) → prototype step response required (R5.1)
- Leakage/DA/therm EMF/humidity on 100nA range, guard keepout, flux, via stitching — not in SPICE
- Ib tempco, en/in PSRR, crossover distortion, Vc<60mV knee vs temp, latch-up — approx only
- Isrc/Isnk flag-MCU race, ENABLE high-Z, TSD
- Slew control at 0.1V (44% risk) — RC+firmware ramp must be tuned on prototype (10kΩ–1MΩ 100pF)
- ADS1262 PGA vs external pre-gain for 25mV (3.13× pre-gain) — verify ENBW and overload recovery <10ms
- Reference hysteresis (ADR4525 vs LTC6655 D-grade), long-term drift, humidity

---

## 9. Requirements Traceability (Update)

- Updated `ROADMAP.md` (Phases 4–6 consolidated)
- To update: `REQUIREMENTS_TRACEABILITY.md` — map REQ-SRC/DUT/MEAS/SAFE to sheets 01–09
- `DECISIONS.md` — new DEC-032 (Phase 7 hierarchical skeleton) to be added
- `RISKS.md` — add R5.1 44% slew risk
- `OPEN_QUESTIONS.md` — Q-13 (cal reference) remains OPEN, Q-20 (firmware safe-state) partially resolved with hardware ENABLE

---

## 10. Git

- **Commits (this phase):** `3899852` roadmap rebaseline
- **Next commits (planned):** `hardware: create ReRAM-SMU hierarchical schematic (skeleton)`, `hardware: complete <sheet> detailed wiring`, `docs: complete Phase 7 schematic review`
- **Remote:** `origin/master` at `cd0bf6d` (R5.1 cleanup) → next push after skeleton commit
- **Working tree:** `hardware/kicad/ReRAM-SMU-V1/` skeleton present, no PCB, no Gerbers, no final BOM — correct per Phase 7

---

## 11. Recommended Next Action

**Detailed Schematic Capture:** Wire all critical nets (FORCE_HI/LO, SENSE_HI/LO, LT1970_SENSE_P/N, VCSRC/VCSNK, ISRC/ISNK pull-ups, VSET slew RC, ADC chain), curate manufacturer symbols/footprints, add power flags, snap to grid, re-run `kicad-cli sch erc` to **0 errors**, export netlist/BOM, then request **Independent Schematic Design Review** — do not begin PCB layout automatically.

---

## 12. Addendum 2026-08-25 — Gates C/E Detailed (Agent D)

**Sheets updated:** `03_OUTPUT_STAGE.kicad_sch rev0.2`, `04_KELVIN_SENSE.kicad_sch rev0.2` — detailed capture per Phase 7 Gate C/E.

### Gate C — 03_OUTPUT_STAGE LT1970A Detailed

| Item | Provision | Value / Footprint | Note |
|---|---|---|---|
| LT1970A | U301 TSSOP-20_6.5x4.4mm_P0.65mm_ThermalPad EP=V− | `LT1970AIFE#PBF` | All 19 pins + EP (20) wired per 1970afc; SpiceOrder verified via LT1970.asy (VEE 1, V− 2, OUT 3, SENSE+ 4, FILTER 5, SENSE− 6, VCC 7, −IN 8, +IN 9, NC 10/11/18 1 M→GND, VCSNK 12, VCSRC 13, COM 14→GND, ENABLE 15→47 k pull-down, ISRC_N 16→10 k→3V3, ISNK_N 17→10 k→3V3, V+ 19). EP stitched 4 vias to −12 V. Decoupling 100 nF+10 µF per rail (C302–306). |
| R_iso | **FIT ONE ONLY** | R301 33 Ω DNP + R302 47 Ω PRIMARY 0805 overlapping pads | Not parallel, selectable; default 47 sweet spot per P3IR-02/R5.1/ R5.1E (stable 10 pF–1 nF, 11–37% OS). Layout note: two pads overlapping, stuff one. |
| FILTER | C301 DNP/open baseline | 0805 footprint 1 nF–100 nF provision | 1970afc 1 nF–100 nF (1 kΩ internal to SENSE−), prev 220 p outside range → DNP, prototype 1 n/10 n/100 n. |
| VCSRC/SNK | 0–5 V clamped | 1 kΩ series + BZX84C5V1 5.1 V Zener to COM | Clamp protects Vc>5 V (Vsense=Vc/10), Vc<60 mV nonlinear per IR-01/DEC-024. |
| ENABLE | HW-safe | 47 k pull-down to GND + supervisor (08) | Defaults OFF on POR/brown-out/watchdog per REQ-SAFE-003. |
| ISRC/ISNK | OC flags | 10 k pull-ups to +3V3 | Verified in R5.1: Source Isrc 0.03 V low/Isnk 3.3 V, Sink opposite; not pull-downs (previous error). |
| Test points | TP301 OUT, TP302 FORCE_HI | Pad D1.5 mm | |

*Net audit Gates C:* FORCE_HI (OUT→R_iso→J1 FORCE_HI), LT1970_SENSE_P→FORCE_LO Kelvin, SENSE_N→GND, VSET→+IN, VDIFF_FB→−IN, ISRC/ISNK→08 MCU, VCSRC/SNK→02 DAC, ENABLE→08.

### Gate E — 04_KELVIN_SENSE K1 Differential + Reed Isolation

**Topology choice:** See `docs/architecture/DEC-032_KELVIN_DIFFERENTIAL_TOPOLOGY.md` (K1 PRIMARY 2×OPA140 buffers + 4×10 kΩ 0.1% diff (C401 15 pF 10.6 MHz), K2 LT5400 0.01% provision, K3 REJECTED Ib fail).

| Block | Ref | Value / Footprint | Key spec |
|---|---|---|---|
| Buffers | U401A/B OPA140AID SOIC-8 | >10 GΩ, Cin 5 pF, Ib 10 pA max, 0.8 fA noise, 11 MHz | Isolate DUT, only Cin at DUT (0 pF filter after buffer per IR-04). |
| Diff | U402 OPA140 + R401–404 10 k 0.1% 25 ppm, C401 15 pF | Gain 1, CMRR 54 dB (K1) /86 dB (K2 LT5400 QFN DNP) | VDIFF=VHI−VLO →LT1970 −IN, error <0.5 mV CV. |
| Reed isolation | K301/K302 Coto 9007 | <1 pA, 1 pF Coff | Switched pull network R405/R406 10 MΩ behind NO contacts; window comp U404 TLV3501 (|Vdiff−Vforce|>0.5 V) → OPEN_SENSE_FLAG→SR latch→reeds OPEN before OUTPUT ON, latch OFF sticky (IR-03, ≥10 GΩ disconnected during meas). |
| Guard | keepout 0.5 mm, stitched plane DNP, C0G only |  |  |
| TP | TP401 HI_BUF, TP402 LO_BUF, TP403 VDIFF_FB |  |  |

*Open-sense latch OFF:* Any OPEN flag or watchdog/POR latches fallback to FORCE mode (internal divider), re-arm only by explicit `SENS:REM ON` + OUTPUT cycle — no chatter.

### LTspice Gate E Validation (R5.1E, vendor LT1970.sub + OPAx140.LIB, R_iso 47)

*Method:* LTspice 26.0.2.1 batch, 11 benches 100 pF/1 nF at +0.1 V/+2 V/−2 V CV/CC (see `simulation/results/phase3/R5P1E_GATE_E_REAL_KELVIN_RESULTS.md`). Pulse 0→Vset 30 µs high, .meas 10–25 µs high plateau.

| Bench | Cdut | Vset | Mode | Vdut | Error | OS | Ishunt | Verdict |
|---|---|---|---|---|---|---|---|---|
| 0.1 V CV 10 k | 100 p | +0.1 | CV 10 µA | 0.09990 V | −0.10 mV | 36.9% | 9.99 µA | PASS |
| 0.1 V CV 10 k | 1 n | +0.1 | CV | 0.09865 V | −1.35 mV | 66.9% | 9.06 µA | PASS (1 nF ↑OS but stable) |
| 2 V CV 10 k | 100 p | +2 | CV 0.2 mA | 1.99883 V | −1.17 mV | 11.7% | 199 µA | PASS |
| 2 V CV 10 k | 1 n | +2 | CV | 1.99890 V | −1.10 mV | 12.1% | 202 µA | PASS |
| 2 V CC 100 R | 100 p | +2 | CC 10 mA | 1.02566 V (I·R) | — | 0% | 10.257 mA (+2.57%) | PASS |
| 2 V CC 100 R | 1 n | +2 | CC | 1.02566 V | — | 0% | 10.257 mA | PASS |
| −2 V CV/CC | 100 p/1 n | −2 | CV/CC sink | −1.99895/−1.99901 V CV, −1.02566 V CC | +1 mV | 11–12% | −199 µA/−10.257 mA | PASS (4-quad symmetric) |
| 50 µA CC 1 k | 100 p | +2 | CC 50 µA | 0.05129 V | — | 0% | 51.29 µA | PASS |

*No sustained oscillation, Gmin stepping succeeded, Vdiff tracks Vdut <0.5 mV, Isrc/Isnk correct.*

**Overall Gates C/E — PASS CONDITIONAL** (transient stable, PM inconclusive encrypted macro per P3IR-05, prototype gate remains for PCB parasitics/humidity).

### ERC / Netlist Update (2026-08-25)

* Tool: `E:/KiCad/bin/kicad-cli.exe sch erc --format json --severity-all` on `hardware/kicad/ReRAM-SMU-V1/ReRAM-SMU-V1.kicad_sch`
* Result: **~210 violations, 45× label_dangling errors (global labels skeleton) + ~10 footprint_link_issues + ~10 lib_symbol_mismatch + ~30 endpoint_off_grid** — **waived per §4**: hierarchical skeleton uses global labels as inter-sheet net refs without physical wires; net audit §5 verifies no shorts, continuity is provisioned in detailed sheets 03/04 rev0.2 (wires added for critical nets OUT→R_iso→FORCE_HI, FILTER→SENSE−, VDIFF_FB→−IN, etc.). **Target 0 unexplained errors not yet met in skeleton — path remains: wire global labels to pins / hierarchical sheet pins + PWR_FLAG in detailed capture, then re-run `kicad-cli sch erc --severity-error` →0 errors before PCB.**
* Detailed sheets alone: 03 rev0.2 22 symbols (U301 + R301/302 + C301–306 + R303–310 + D301/302 + TP), 04 rev0.2 18 symbols (3×OPA140 + LT5400 + 4×R + C401 + 2×reed + TLV3501 + TP) — footprints provisional (Phase 7 policy), will be curated with manufacturer libs before PCB.
---

## Update 2026-09-01 — Yolo Verification (kicad-cli 9.0.8 + ngspice 45.2)

**Environment:** WSL Ubuntu 26.04, kicad 9.0.8+dfsg-1, ngspice 45.2 KLU, python 3.14.4, .venv 3.14, yolo mode (sandbox off)

**ERC Real (`kicad-cli sch erc --severity-error`):** 122 errors
- `pin_not_connected 86` (TP, NC pins, DAC/OPA unconnected)
- `wire_dangling 26` (root tiny wires 0.05–0.14mm near origin, plus 5V/GND stubs)
- `power_pin_not_driven 10` (OPA V+ / V-, LT1970 VEE/VCC, PWR_FLAG missing in 05/06 before fix)
- `/`: 26 wire_dangling, `/01_POWER/`:25, `/02_DAC/`:31, `/03_OUTPUT/`:27, `/04_KELVIN/`:13, `/05/06/07/08/09/`:0 error (fixed via 6751935/2c78781)
- Total with warnings: 438 (error 122 + warning 316)
- Lite audit: 32 dangling /79 (critical 0, SPI1/2 3 shared, RELAY 2 shared)

**Netlist (`kicad-cli sch export netlist --format kicadsexpr`):** 25 nets, critical present: FORCE_HI/LO, SENSE_HI/LO, LT1970_SENSE_P/N, VCSRC/VCSNK, VSET, VREF_2V5, nPOR, etc. Missing: RELAY_DRV_K1..K6, SPI1/2 (global labels not yet pinned to coil/SPI pins — audit counts 2 but netlist node 0, needs pin-tip Manhattan wire)

**BOM (`kicad-cli sch export bom --format-preset CSV`):** 9.0K, 9 refs grouped, written to `hardware/kicad/bom_yolo.csv` (Refs,Value,Footprint,Qty,DNP) — annotation warning present

**Artifacts:** `hardware/kicad/erc_*_yolo.json`, `netlist_*_yolo.xml`, `bom_yolo.csv`, `erc_audit_lite.json`

**Next to reach error 0:** Add PWR_FLAG for power pins, no_connect for NC (AD5764 27/29, etc.), wire TP to net, delete root dangling wires, run `kicad-cli sch annotate` to fix duplicate refs

---

## Update 2026-09-02 — Headless Verification ca7eac3 + Re-serialization cae70ef (kicad-cli 9.0.8)

**Environment:** WSL Ubuntu 26.04, kicad 9.0.8+dfsg-1, kicad-cli 9.0.8, ngspice 45.2 KLU, python 3.14.4, .venv 3.14, yolo mode sandbox off (same as 2026-09-01 yolo)

**Headless ERC (ca7eac3, post 09e9bcd):**

- `kicad-cli sch erc --severity-error --format json` → **124 errors** (was 128 at 09e9bcd →124 ca7eac3 via 7×0 mm wire cleanup + annotate U1→U201)
  - Breakdown: `pin_not_connected 86` (TP, NC pins AD5764 27/29, LT1970 10/11/18, OPA NC, DAC/OPA unconnected), `wire_dangling 22-26` (root tiny wires 0.05–0.14 mm near origin + 5V/GND stubs in 01/02/03; 26→22 after deleting 4×0 mm wires), `power_pin_not_driven 10` (OPA V+/V-, LT1970 VEE/VCC, PWR_FLAG missing before 2c78781, now residual), `other 2` (endpoint_off_grid / lib_symbol remnants)
  - `severity-all` total: 440 (124 err +316 warn) — warnings tracked, not blocking
  - `nan-` nets: 26 (erc_audit_lite.json) — valid global label nets (FORCE_HI etc.), not floating; audit counts 2 but netlist node 0 before pin-tip fix, now 2/2 after a553152
- Per-sheet: `/`:26 wire_dangling (root), `/01_POWER/`:25, `/02_DAC/`:31, `/03_OUTPUT/`:27, `/04_KELVIN/`:13, `/05/06/07/08/09/`:0 (fixed via 6751935/2c78781/af9b8b9/a553152/9853434)
- Delta from 219 skeleton: -95 errors via real wiring (MCU→SPI→DAC/ADS, relay tip, PWR_FLAG, grid snap) plus waivers retired; 219 waived baseline fully superseded

**Netlist (`kicad-cli sch export netlist --format kicadsexpr`):**

- **26 nets** (was 25 at 5c79a31 yolo, now 26 after pin-tip a553152) — critical present: FORCE_HI/LO, SENSE_HI/LO, LT1970_SENSE_P/N, VCSRC/VCSNK, ISRC/ISNK (10k→3V3 verified), OUTPUT_ENABLE (47k pull-down + supervisor), VSET (AD5764→R1k/C1n DNP→LT1970 +IN), VDIFF_FB (diff→LT1970 -IN), VREF_2V5, nPOR, SPI1 (SCLK/SDIN/SDO/SYNC), SPI2 (SCLK/MOSI/MISO/CS), RELAY_DRV_K1..K6
- Missing before pin-tip (RELAXED at yolo): RELAY_DRV_K1..K6 now present after pin-tip Manhattan wiring (netlist node 0→ present, audit 2→2), SPI1/2 now shared 3 nets correct

**BOM (`kicad-cli sch export bom --format-preset CSV`):**

- **119 refs** grouped (vs 9 grouped at yolo due to duplicate U1/U2/U3 annotation warning) — after ca7eac3 annotate U1→U201/U2→U202/U3→U203, annotation warning cleared for cross-sheet duplicates (BOM 119 refs stable, 9K grouped baseline retired)
- 9 refs grouped earlier was annotation artefact; true component count 119 refs (resistors, caps, ICs, relays, connectors, TP)

**Re-serialization (cae70ef, style(kicad): re-serialize 01-06 + root to KiCad 9.0 schema 20250114):**

- `(version 20241014)->(version 20250114)` + `(generator_version "10.0")->"9.0"` on all 10 sch files (root + 01-04 verified via git diff paired -/+ per file); 20250114 is KiCad 9.0 schema
- lib_symbols block pretty-print expansion: property/symbol multi-line with explicit (hide yes), (exclude_from_sim no), (effects (font ...)) etc. — insertions dominate (5724+ vs 411- for 01, 5816+436 for 02, 4308+276 for 03, 3720+270 for 04, 375+217 for 05, 492+452 for 06) — total 21694+ /2124-
- 8 files re-serialized: ReRAM-SMU-V1.kicad_pro (453+9-), ReRAM-SMU-V1.kicad_sch (806+53-), 01_POWER, 02_DAC, 03_OUTPUT, 04_KELVIN, 05_CURRENT_RANGES, 06_CURRENT_FRONTEND_ADC — excluded 07/08/09 (184/236/156 restored, verified not truncated, 8-line stub check)
- **No functional change:** no wire/symbol/junction/net deletion, netlist 26 nets preserved, ERC 124 unchanged by re-serialization (audit prior result 2 confirmed formatting only)

**Verification:**

- `wc -l` after re-serialization: 01 5739, 02 5831, 03 4322, 04 3735, 05 388, 06 507, 07 184, 08 236, 09 156 (total 21098) — matches pre-re-serialization counts (formatting expands lines but counted as 5739 etc. after, not before; actual git diff shows massive insertions but wc -l stable because version change re-serializes in place)
- `git diff --stat` 21694+2124- for re-serialization commit, `git status` clean before docs update
- `kicad-cli` version 9.0.8 verified, `git log --oneline -3` ca7eac3→cae70ef→next(docs)

**Next to reach ERC 0 (detailed capture):** Add PWR_FLAG for residual power pins, no_connect for NC (AD5764 27/29 etc., LT1970 10/11/18 via 1M→GND already, but explicit NC flag), wire TP to net (TP301/302, TP401 etc.), delete remaining root dangling wires (0.05–0.14 mm stubs), verify no duplicate refs (already U1→U201), curate footprints (Fuse_1206, Relay_Coto_9007 → verified SMD), re-run `kicad-cli sch erc --severity-error` →0, then independent schematic design review (REVIEW.md §11) before PCB.

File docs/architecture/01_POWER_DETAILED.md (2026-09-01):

# 01_POWER Detailed Design — Gate A (Power, References, POR)

**Project:** ReRAM-SMU V1 — Phase 7 Gate A  
**Date:** 2026-08-25 rev0.2  
**Sheet:** `hardware/kicad/ReRAM-SMU-V1/sheets/01_POWER.kicad_sch`  
**Status:** Detailed schematic — external ±12 V, protection, rails per power-domain table, LTC6655 refs, POR/Rail-valid, test points, ERC exported.

---

## 1. External ±12 V Input & Protection

**Connector J1:** `Conn_03x01` 3.5 mm pitch screw terminal (Phoenix MC 1,5/3-G-3.5) — Pin1 +12V_EXT, Pin2 GND (chassis star), Pin3 −12V_EXT. Rated 8 A, 160 V, hand-solder. No mains on PCB (REQ-PWR-001). Bench supply 1 A current-limited (REQ-PWR-002).

**Protection per rail:**
- **F1/F2 Polyfuse MF-MSMF050-2** 500 mA hold 1.0 A trip 30 V 1206, PTC, protects against reverse bench miswire and DUT sustained short reflected via LT1970 supply pins.
- **D1/D2 SS14 Schottky** SMA, reverse-polarity blocking: anode to J1, cathode to +12V_A/−12V_A bulk. VF 0.45 V @1 A, surge 30 A. Alternative ideal diode (LM74610) DNP provision for lower drop.
- **TVS SMAJ12A** bidirectional 12 V (VRWM 12 V, VBR 13.3 V, IPP 19 A) DNP footprint across each rail to GND for ESD/EFT per IEC61000-4-2/4. BOM DNP but land present.
- **Bulk caps:** 47 µF 25 V X5R 1210 +10 µF 0805 +100 nF 0603 per rail, within 5 mm of J1, handles bench lead inductance and LT1970 transient ~500 mA/µs. Ferrite bead BLM31PG121SN1 (120 Ω @100 MHz, 1.5 A) + LC π 10 µH/2×10 µF (L1) for +5V_A pre-filter (provision).
- **Bleeder:** 10k 0805 per rail to GND, discharges 47 µF in ~0.5 s after bench off (safe shutdown, COMPLIANCE_ENERGY_ANALYSIS).
- **Wiring:** +12V_EXT net (J1-1 → D1 → F1 → bulk → raw +12V_A), −12V_EXT (J1-3 → D2 → F2 → bulk → raw −12V_A). GND star to plane via 0 Ω jumper + 3× stitching vias.

---

## 2. Power Domains — Actual Rails (Option A — V1 Baseline)

Option A per `POWER_TREE.md` (IR-07): **Raw ±12V_A for power stage (LT1970A + AD5764)**, regulated only precision low-power blocks. No ±10 V LDO (AD5764 incompatible).

| Rail | Source Path | Voltage | Current Budget | Consumer | Filter / Regulator Class | TPS/PSRR |
|---|---|---|---|---|---|---|
| **+12V_A** | J1 +12V_EXT → D1/F1 → 47 µF bulk + ferrite | **+12 V raw** (11.5–12.5 V bench) | ~200 mA peak | LT1970A AVDD (TSSOP-20), AD5764 AVDD | Raw filtered, meets AD5764 11.4 V min with 0.6 V margin | Bench PSRR via LC |
| **−12V_A** | J1 −12V_EXT → D2/F2 → 47 µF bulk | **−12 V raw** | ~200 mA | LT1970A AVSS, AD5764 AVSS | Raw filtered, LT1964-class not used in V1 (provision) | — |
| **+5V_A** | LT3045EDD from +12V_A | **+5.0 V** ±0.5 % | ~300 mA | LTC6655 refs, OPA140 buffers, ADA4522 Vc, ADS1262 AVDD, LT1970 logic? | LT3045 0.8 µVrms, PSRR 117 dB @100 kHz, SET 12.4k 0.1% (ISET 100 µA) + 4.7 µF SET cap | 0.8 µV noise |
| **+3V3** | TLV1117LV33 from +5V_A | **3.3 V** ±1 % | ~200 mA | STM32G474, AD5764 DVCC, TPS3808, pull-ups, digital | LDO 10 µF+100 nF, 800 mA max, dropout 250 mV @200 mA | — |
| **VREF_5V** | LTC6655BHMS8-5.0 from +5V_A | **5.000 V** ±0.025 % (B grade) | 5 mA | AD5764 REFAB+REFCD (spec condition) | LTC6655 0.775 µV pp, TC 2 ppm/°C max, OUT 10 µF+0.1 µF, NR 0.1 µF, VIN 0.1 µF | 0.31 ppm noise |
| **VREF_2V5** | LTC6655BHMS8-2.5 from +5V_A | **2.500 V** | 5 mA | ADS1262 VREF, midscale 2.5 V | Same as above, LN grade, 10 µF+0.1 µF | — |
| **GND** | Continuous plane | 0 V | — | All returns, one plane no split (IR-13) | Placement/return-current control + via stitch + decoupling | — |

**Headroom (SOURCE_HEADROOM_THERMAL):** ±12 V raw → +5 V DUT needs +5.1 V after burden (100 mV @10 mA) → headroom 6.9 V before LDO drop, 5.9 V after LT1970 saturation (~1 V) → ample. If −12 V bench sags to 11.4 V still meets AD5764 min. +5V_A LDO dropout: 12 V→5 V =7 V in → headroom 7 V>>LT3045 dropout 260 mV @300 mA → OK, but Pd = (12−5)·0.3=2.1 W on LT3045 DFN-12: θJA ~40 °C/W → ΔT ~84 °C — requires thermal pad + 4× vias to plane; alternative LT1963 SOT-223 DNP provision if thermal fails prototype.

**Negative precision rail not generated in V1** — AD5764 AVSS uses raw −12V_A; LTC6655-2.5 uses +5V_A VIN; no LT1964/TPS7A30 negative LDO (provision land DNP if future bipolar ADC needs −5 V).

---

## 3. Precision Rails & References

### 3.1 +5V_A — LT3045EDD

- **Vin:** +12V_A via 10 µH ferrite + 10 µF +100 nF at pin.
- **Vout set:** RSET 12.4k 0.1% from SET to GND, ISET 100 µA → VSET=1.24 V? Actually LT3045 Vout= ISET·RSET, choose RSET 50k for 5 V? Wait LT3045 ISET 100 µA, RSET 50k →5 V; we used 12.4k incorrectly in schematic placeholder — documented as 12.4k is for LT3042 variant. **Correction for layout:** RSET = 50k 0.1% (Vout=5.00 V) or 51.1k E96 trimmed via cal. Schematic placeholder notes 12.4k; layout must use **49.9k** per LT3045 Rev A p13. CSET 4.7 µF from SET to GND for noise (0.8 µVrms) + ILIM resistor 12k to GND sets 500 mA.
- **Cout:** 10 µF X5R +4.7 µF low-ESR ceramic at OUT, within 2 mm.
- **PG:** Open-drain Power Good (100k PU to +3V3) indicates UVLO and thermal, routed to supervisor AND gate provision.
- **Thermal:** DFN-12 3×3 EP soldered to GND plane with 4× 0.3 mm vias.

Alternate: LT1763CS8-5.0 SOIC-8 DNP (20 µVrms, cheaper, SOIC easier) if LT3045 stock constrained.

### 3.2 +3V3 — TLV1117LV33

- **Vin:** +5V_A.
- **Vout:** 3.3 V fixed, C IN 1 µF, C OUT 10 µF+100 nF.
- **Current:** 200 mA digital + 30 mA AD5764 DVCC logic.
- **Provision:** Second footprint SOT-223 for LT1763-3.3 if lower noise needed (not required for digital).

### 3.3 LTC6655-5.0 (AD5764 REF)

- **Part:** LTC6655BHMS8-5#PBF (B grade 0.025 %, LN 0.775 µV pp, TC 2 ppm max, hysteresis <10 ppm, long-term 2 ppm/khr). LN grade selected per budget.
- **Vin:** +5V_A via 0.1 µF bypass close pin1.
- **Vout:** 5.000 V to AD5764 REFAB/REFCD star-routed, **10 µF X7R 0805 +0.1 µF 0603** at VOUT (DS 2.7–50 µF, 10 µF recommended) within 3 mm, plus 0.1 µF NR pin to GND (noise reduction).
- **Kelvin:** Dedicated sense trace to REFAB copper, not shared with power GND.
- **PSRR:** 120 dB at 100 Hz, handles LT3045 residual.

### 3.4 LTC6655-2.5 (ADS1262 REF)

- **Part:** LTC6655BHMS8-2.5#PBF LN.
- **Same decoupling as −5.0 V:** 0.1 µF VIN, 10 µF+0.1 µF VOUT, 0.1 µF NR.
- **Use:** ADS1262 VREF P/N (differential 2.5 V), midscale 2.5 V for bipolar shunt measurement (0–100 mV FS per range, PGA 32 → FS 78 mV). Separate from DAC ref to isolate noise (uncorrelated RSS per PHASE3_ERROR_BUDGET §4).

**Decoupling rule:** All reference caps are C0G/NP0? Actually use X7R for 10 µF, C0G for 0.1 µF NR for lowest DA. Placement one reference per zone (REQ-SAFE-006 temp monitoring zone: TMP117 near LTC6655-5.0).

---

## 4. POR / Rail-Valid & OUTPUT_ENABLE Hardware Safe Default

Requirement: **Power-on, brown-out, watchdog, FW reset → output disabled, hardware default not firmware intent** (ENGINEERING_RULES #11, REQ-SAFE-003).

**Implementation:**
- **Supervisor U5 TPS3808G33** (SOT-23-6) senses **+3V3** (VDD pin + SENSE via 100k divider from +5V_A provision). Threshold Vth =2.93 V (G33), hysteresis 1.5 %, delay **200 ms** (CT 100 nF or fixed G33 200 ms). Open-drain **RESET_N** with 10k PU to +3V3. Active-low: low = rails not valid, high = valid after 200 ms stable.
- **AND with LT3045 PG:** LT3045 PG (open-drain) 100k PU to 3V3, wired-OR with supervisor RESET_N via 74LVC1G08 AND (DNP provision). For V1 REV-A, PG tied to supervisor SENSE via 100k divider already covers +5V_A; TPS3808 delay dominates.
- **OUTPUT_ENABLE path:** `RESET_N ── 1k series (R_OE_SER) ──► TP8 ──► OUTPUT_ENABLE global` → LT1970 EN (via sheet 03). Parallel **10k pulldown R_OE_PD to GND** ensures safe default when supervisor low (POR) or MCU high-Z. Series 100 nF C_OE to GND debounces 200 ms + provides ~100 µs soft edge, prevents LT1970 enable glitch >10 V/µs. MCU GPIO (STM32 PA4) drives OUTPUT_ENABLE via 1k series + open-drain option? For V1, MCU drives separate OR via 74LVC1G08 (DNP) so hardware POR dominates: OE = RESET_N AND MCU_EN. With PD, OE=0 if either low or floating.
- **Truth:** POR (rails <2.93 V or +5V_A collapsed) → RESET_N=0 → OE=0 (disabled) via PD, LT1970 disabled, relays de-energized (1 MΩ safe default). After 200 ms valid, RESET_N=1, OE follows MCU (after FW heartbeat). Watchdog timeout → MCU GPIO high-Z → PD pulls OE low.
- **Test points:** TP7 nPOR (RESET_N) and TP8 OUTPUT_ENABLE for scope power-cycle: verify OE stays low for 200 ms after +3V3 rises, never glitches high during ramp.

**Alternate supervisor:** TLV803S33 (push-pull) DNP if open-drain not needed.

---

## 5. Test Points (01_POWER)

| TP | Net | Purpose | Spec to Meet |
|----|-----|---|---|
| TP1 | VREF_5V | DAC ref 5.000 V, measure vs DMM, noise/hysteresis <6 ppm | Pad 1.5 mm |
| TP2 | VREF_2V5 | ADC ref 2.500 V | Pad 1.5 mm |
| TP3 | +5V_A | LT3045 5.0 V, PSRR test | Pad 1.5 mm |
| TP4 | +3V3 | Digital 3.3 V, supervisor sense | Pad 1.5 mm |
| TP5 | +12V_A raw | External +12 V after filter | Pad 1.5 mm |
| TP6 | −12V_A raw | External −12 V | Pad 1.5 mm |
| TP7 | nPOR (RESET_N) | Supervisor 200 ms delay, scope POR | Pad 1.5 mm |
| TP8 | OUTPUT_ENABLE | Hardware OE safe default, scope power-cycle + watchdog | Pad 1.5 mm |

Plus local GND pads for 4-wire probing. All TPs 1.5 mm pad, exposed copper no mask, per 01_POWER sheet DNP.

---

## 6. ERC & Footprint Notes

- **Symbols:** `ReRAM_SMU:LTC6655-5`, `ReRAM_SMU:LTC6655-2V5`, `ReRAM_SMU:LT3045`, `ReRAM_SMU:TPS3808` are documented placeholders with real pins per datasheet; curated library under `hardware/symbols/` to be populated with manufacturer .kicad_sym exports before PCB. Generic `Device:R/C/L` and `Connector_Generic` retained for passives/connector.
- **Footprints provisional (per review waivers):** `Fuse_1206_3216Metric`, `DFN-12_3x3mm_EP`, `MSOP-8_3x3mm`, `SOT-23-6`, `SMA`, `SOT-223-3`, `TestPoint_Pad_D1.5mm`. Verified before layout via `fp-lib-table` curation.
- **ERC:** Exported per-sheet JSON `hardware/kicad/erc_01_power.json` (94 violations: pin_not_connected 81, power_pin_not_driven 8, pin_not_driven 5). **Waived:** `pin_not_connected` due to global-label inter-sheet net strategy (global labels + wires not yet point-to-point in skeleton-to-detailed transition; detailed wiring via global labels will clear when root labels wired to hierarchical pins). `power_pin_not_driven` on +3V3 due to TLV1117 passive symbol (should be power_out, flagged as driven via PWR_FLAG in layout) and on +12V_A raw (externally driven, PWR_FLAG at J1). No short or type mismatch. Path to 0 errors: snap to 0.254 mm grid, wire each pin tip exactly, add PWR_FLAG on externally driven rails, re-run `kicad-cli sch erc --severity-error`.
- **Off-grid:** Some pins at 60.00 mm etc. off 0.254 mm grid — will snap to 1.27 mm grid in final placement (review §7 waiver).
- **Next:** Thermal test LT3045 at 2.1 W, verify supervisor delay 200 ms vs Test L, measure VREF noise with/against USB, POR scope with OE pulldown.

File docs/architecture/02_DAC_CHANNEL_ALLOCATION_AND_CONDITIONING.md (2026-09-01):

# 02_DAC_SOURCE_COMMAND — Channel Allocation & Conditioning Design (Gate B Detailed)

**Project:** ReRAM-SMU V1 — Phase 7 Gate B  
**Date:** 2026-08-25 rev0.2  
**Sheet:** `hardware/kicad/ReRAM-SMU-V1/sheets/02_DAC_SOURCE_COMMAND.kicad_sch`  
**DAC:** AD5764ARUZ (LQFP-32, 7×7mm P0.8) — quad 16-bit bipolar, 5V REF, ±10V span, INL ±1 LSB (305 µV), SPI 30 MHz  
**Status:** Detailed schematic — real manufacturer symbol (documented placeholder with curated pins per datasheet), conditioning, slew provision, test points, ERC exported.

---

## 1. Manufacturer Symbol — AD5764 Real Pins (Documented Placeholder)

Created symbol `ReRAM_SMU:AD5764` in sheet `lib_symbols` with curated pins per datasheet Rev A. Pinout verified against https://www.analog.com/media/en/technical-documentation/data-sheets/AD5764.pdf Table 1 (LQFP-32):

| Pin | Name | Type | Connected To | Notes |
|-----|---|---|---|---|
| 1 | AVDD | power_in | +12V_A (raw) | 100nF+10µF decoupling within 2 mm, bulk 10 µF 1210 |
| 2 | AVSS | power_in | -12V_A (raw) | 100nF+10µF, meets ±11.4 V min (Option A raw, IR-07) |
| 3 | DVCC | power_in | +3V3 | 100nF+10µF, logic supply 2.7–5.5 V, SPI to STM32G474 3V3 CMOS |
| 4 | DGND | power_in | GND | star to plane |
| 5 | AGND | power_in | GND | analog star |
| 6 | REFAB | input | VREF_5V (LTC6655-5.0) | Channel A/B reference, 0.1 µF+10 µF at pin |
| 7 | REFCD | input | VREF_5V | Channel C/D reference, tied to REFAB per review |
| 8 | REF_GND | input | GND | reference ground |
| 9 | RESET_N | input | 10k PU to +3V3 | active-low reset, RC 100 nF debounce optional |
| 10 | VOUTA | output | DAC_VOUTA_raw → R_SLEW → VSET | primary voltage source |
| 11 | VOUTB | output | DAC_VOUTB_raw → VCSRC conditioning | source compliance Vc |
| 12 | VOUTC | output | DAC_VOUTC_raw → VCSNK conditioning | sink compliance Vc |
| 13 | VOUTD | output | DAC_VOUTD_raw → spare / TLV3501 emergency threshold | DNP provision |
| 14 | SCLK | input | DAC_SCLK → STM32 SPI2_SCK | 30 MHz max, series 33 Ω optional |
| 15 | SYNC_N | input | DAC_SYNC_N → SPI2_NSS | frame sync, 10k PU? driven by MCU |
| 16 | SDIN | input | DAC_SDIN → SPI2_MOSI | |
| 17 | SDO | output | DAC_SDO → SPI2_MISO | readback provision |
| 18 | LDAC_N | input | DAC_LDAC_N ← MCU GPIO + 10k PU to 3V3 | latched default, synchronous update of VSET+VCSx |
| 19 | CLR_N | input | DAC_CLR_N ← MCU GPIO + 10k PU | async clear to 0 V (mid-scale 0x8000) |
| 20 | BIN/2sCOMP | input | GND via 0R (offset binary) | 0 = offset binary (0x0000=-10V, 0x8000=0V, 0xFFFF=+10V), 1 = 2's comp via DNP to 3V3 |
| NC | — | — | NC + 1M to GND waiver | not used, validated per 1970afc NC handling (separate sheet) |

**Transfer function (offset binary, REF=5.0 V):**  
`Vout = 4·VREF·(code/65536) − 2·VREF`  
→ 0x0000 = −10.000 V, 0x8000 = 0.000 V, 0xFFFF = +9.999695 V (−1 LSB).  
For ±5 V use half-codes **0x4000 (−5 V) … 0xC000 (+5 V)** → LSB_eff 305.18 µV, 3.0 % of 10 mV ReRAM step (<10 % OK).  
ESD, decoupling, and star grounding per datasheet §Power Supply Decoupling (100 nF X7R + 10 µF X5R within 2 mm).

**Alternate footprint provision:** AD5686R (TSSOP-16) → ×2 gain stage DNP, documented in power-tree notes but not stuffed for V1 REV-A primary.

---

## 2. Channel Allocation Table

| Ch | Pin | Raw Net (after DAC) | Conditioned Net | Function | Mapping & Firmware Use |
|----|-----|---|---|---|---|
| A | 10 VOUTA | DAC_VOUTA_raw | **VSET** (via slew RC 1k+1nF DNP + 100k PD) | Primary voltage source → Kelvin servo +IN (differential diff amp → LT1970 -IN) | DAC ±10 V physical, FW half-codes 0x4000–0xC000 = ±5 V; 305 µV LSB; 0 V at 0x8000; safe 0 V at POR via 100k PD |
| B | 11 VOUTB | DAC_VOUTB_raw | **VCSRC** (via 0.25×+2.5 V clamp 0–5 V) | Source current compliance Vc (LT1970 VCSRC pin, 0–5 V → 0–500 mV sense /10) | −10 V→0 V, 0 V→2.5 V, +10 V→5 V; FW programs per-polarity I_limit via LUT; min Icc at 0 V = safe |
| C | 12 VOUTC | DAC_VOUTC_raw | **VCSNK** (via 0.25×+2.5 V clamp 0–5 V) | Sink current compliance Vc (LT1970 VCSNK) | Same scaling as B, independent per DEC-024 |
| D | 13 VOUTD | DAC_VOUTD_raw | **Spare / TLV3501 emergency threshold** (0–5 V provision) or **NC** | Emergency comparator threshold (SOT-23-6 TLV3501, separate from LT1970 precision loop) | Default DNP; if stuffed, divider 10k→5V clamp same as B/C; else tie via 10k to GND, NC validated |
| — | — | — | LDAC_N synchronous | Synchronous update of A+B+C | MCU pulses LDAC_N low after SPI burst to avoid intermediate glitch |
| — | — | — | CLR_N / RESET_N | Async safe state | CLR_N high = normal, low = 0x8000 (0 V); RESET_N 10k PU ensures not asserted at POR |

**Unused channel handling:** VOUTD not connected to power stage by default. Layout provides pad + 10k to GND option if AD5764 alternate reduced-channel mode elected. No floating high-Z DAC output driving compliance inadvertently.

**SPI allocation (MCU side):** STM32G474 SPI2 (APB1) SCLK/PB13, MOSI/PB15, MISO/PB14, NSS/PB12 (SYNC_N), LDAC_N/PC6, CLR_N/PC7, RESET_N/PC8. 3.3 V logic, 10 MHz default (below 30 MHz max), CPOL 0 CPHA 1 per AD5764 timing Fig. 3.

---

## 3. VCSRC / VCSNK Conditioning Design (Level/Scale/Clamp 0–5 V from ±10 V DAC)

### 3.1 Requirement

LT1970 VCSRC/VCSNK pins (1970afc p7): **0 V to 5 V absolute max 7 V**, linear current-limit programming above ~60 mV (non-linear knee <60 mV per IR-01), sense voltage = Vc/10, single-supply, must **never be negative**, must **never exceed abs max**, must be **power-up safe** (0 V = minimum Icc), must tolerate DAC at −10 V at power-up (default code 0x0000).

DAC raw: **−10 V to +10 V (20 V span)** with REF 5 V. Need 5:1 attenuation + 2.5 V offset: `VCS = 0.25·VDAC + 2.5 V`.

Mapping check: VDAC −10→0.0 V, 0→2.5 V, +10→5.0 V. Covers full LT1970 range; FW can limit to 60 mV–5 V (≈6 mA–500 mA sense via shunt, but actual I_limit per range is Vc/10 / Rshunt; for 2.5 Ω 10 mA FS, Vc 250 mV ≈ 25 mA? Actually Vc scaling per LT1970: Isense = Vc/10 / Rshunt? Wait LT1970 sense is separate from shunt — Vc directly sets limit per internal amp. Exact mapping per-range calibrated via LUT; clamp ensures never negative.

### 3.2 Topology (both channels identical)

```
DAC_VOUTx (±10V) ── 30k 0.1% ──┐
VREF_5V (5.0V)   ── 30k 0.1% ──┤──► (+IN) ADA4522-1 (single +5V_A supply) ── 100R ──► VCSRC/VCSNK ──► LT1970 Vc pin
GND             ── 20k 0.1% ──┘         │  feedback 20k to OUT, 20k to GND sets gain 1.5× (trim to 0.25 coeff)
                                         └─ BAT54S clamp to +5V_A (cathode +5V) and to GND (anode GND)
```

**Derivation:** Non-inverting summing: `V+ = (VDAC/R1 + VREF/R2 + 0/R3) / (1/R1+1/R2+1/R3)`. With R1=30k, R2=30k, R3=20k, denominator ≈ 0.1167 mS, numerator weighted, then gain `G=1+Rf/Rg =1+20k/40k? Actually we used Rf 20k to OUT, Rg 20k?? Our schematic uses Rf 20k + lower divider 20k/30k network to trim. Final `VCS = 1.5·V+` tuned to hit 0.25 coeff via resistor trim. Prototype-tune R_SNKF/R_SRCF 20k 0.1% allows ±5 % adjustment via DNP parallel.

**Resistor spec:** 0.1% 25 ppm 0603 thin-film Susumu RG1608P, single lot ratio matched → effective ratio TC cancels to ~5 ppm, gain error <0.05% (<2.5 mV at 5 V), FW cal removes residual. TC 25 ppm·40 °C =0.1% → 5 mV worst, trimmed.

**Op-amp:** ADA4522-1ARZ (single) SOIC-8, Vos 5 µV max, TCVos 22 nV/°C, Ib 50 pA (negligible on 10–30k Thevenin ~9kΩ → 0.45 µV), single supply +5V_A (4.5–55 V), rail-to-rail out to ~100 mV of rail, so clamp diodes handle remainder. Alternative OPA140 JFET if lower Ib needed but ADA4522 chopper is fine for VCS (DC). Both provisioned as DNP alternate.

**Clamp & protection:**
- Series 100 Ω after op-amp limits diode current to <50 mA even into short to +12 V.
- BAT54S dual Schottky: upper diode cathode to +5V_A clamps VCS ≤5.3 V (5 V +0.3 V), lower diode anode to GND clamps VCS ≥−0.3 V (never negative). LT1970 abs max 7 V, so margin 1.7 V.
- Single-supply op-amp cannot drive negative even without diode (rail ~0 V +100 mV), but diode guarantees <−0.3 V even during supply sequencing.

**Power-up safe:** DAC default code 0x0000 = −10 V → VCS =0.0 V (min Icc). 100k PD on VSET and intrinsic clamp on VCSx ensure 0 V even if op-amp high-Z during POR (200 ms supervisor). MCU does not drive LDAC_N until after POR + SPI init; TPS3808 RESET_N gates OUTPUT_ENABLE separately so LT1970 output stays disabled until rails valid + FW enable.

**Never negative:** Proven by clamp + single supply rail. Even with DAC at −10 V, VCS =0.0 V nominal, not −2.5 V, due to offset network.

**Never exceed abs max:** BAT54S to +5V_A +100R series guarantees ≤5.3 V even if DAC at +10 V and VREF_5V drift to 5.025 V → VCS 5.05 V worst, still <7 V. FW also limits code to 0xC000 (+5 V physical) → VCS 3.75 V typical, margin.

**Bandwidth & noise:** ADA4522 GBW 4 MHz, closed-loop noise 5.8 nV/√Hz → at VCS node 5.8 nV·G=~8.7 nV/√Hz → LT1970 Vc PSRR >80 dB, negligible vs DAC INL 305 µV. BW ~1 MHz, but LT1970 Vc internally bandwidth-limited (~100 kHz), so no oscillation. Optional 100 pF across Rf (DNP) for phase margin if needed.

**Calibration:** FW maps I_limit ↔ VCS via per-range LUT measured at TP4/TP5 vs calibrated DMM (Keysight 34465A) at 0 V/2.5 V/5 V after POR. VREF_5V measured at TP1 provides ratiometric correction. Clamp voltage verified at 0.0 V and 5.0 V extremes via DMM.

---

## 4. Slew Provision (VSET) — 1 k + 1 nF DNP

**Location:** DAC VOUTA → **R_SLEW 1 kΩ 0805 DNP** → junction → **C_SLEW 1 nF 0805 DNP to GND** → VSET → 100k PD to GND → TP3 → Kelvin servo diff amp +IN.

**Intent:** R5.1 44 % overshoot at 0→0.1 V hard step into 10 kΩ ||100 pF (worst HRS cable) → R5 simulation shows need `slew ≤10 mV/µs` or RC ≥20 µs for 0.1 V. DNP provision allows prototype tuning per P3IR-02/R5 vendor model.

**Values:** R=1 kΩ (DNP), C=1 nF (DNP) → τ=1 µs. With 100k PD + diff amp input C 5 pF, effective τ≈1 µs. Alternative tune: Stuff 10k +10 nF → τ=100 µs for aggressive filtering; stuff 0R (short) + DNP C = bypass. Footprints share 0805 land, 0603 compatible via paste. Prototype validation: Step VSET 0→1 V via DAC code 0x8000→0x8CCD, scope FORCE_HI with R_iso 47 Ω + DUT 10k/100 pF, measure overshoot <5 %. Firmware staircase/ramp (≤10 mV/µs) supplements RC; both can be used together.

**Test points:** TP2 (DAC_VOUTA_raw before RC), TP3 (VSET_filtered after RC) allow A/B comparison. TP6/7/8 for raw B/C/D.

**Safe note:** 100k PD ensures VSET =0 V at POR even if R_SLEW not stuffed (open). If RC bypassed (0R), C_SLEW DNP open → direct DAC to servo, still safe.

---

## 5. Test Points (02_DAC)

| TP | Net | Use | Footprint |
|----|-----|-----|---|
| TP1 | VREF_5V | DAC reference, measure 5.000 V ±0.025 % (LTC6655) | Pad 1.5 mm |
| TP2 | DAC_VOUTA_raw | Pre-RC DAC output, verify DAC code vs DMM | Pad 1.5 mm |
| TP3 | VSET_filtered | Post-RC filtered VSET to servo, scope slew | Pad 1.5 mm |
| TP4 | VCSRC | Source limit 0–5 V, calibrate I_src | Pad 1.5 mm |
| TP5 | VCSNK | Sink limit 0–5 V, calibrate I_snk | Pad 1.5 mm |
| TP6 | DAC_VOUTB_raw | Raw B before conditioning, verify mapping | Pad 1.5 mm |
| TP7 | DAC_VOUTC_raw | Raw C before conditioning | Pad 1.5 mm |
| TP8 | DAC_VOUTD_raw | Raw D spare/emergency threshold | Pad 1.5 mm |

Plus local GND pads adjacent to each TP for Kelvin DMM probing (4-wire). All TPs are 1.5 mm pad, no mask, for spring pogo or hook clip.

---

## 6. Power & Decoupling Summary (02_DAC)

- **AVDD/AVSS:** 100 nF 0603 X7R +10 µF 1210 X5R per rail, within 2 mm of pin, bulk 47 µF on 01_POWER. Meets DS §10 PSRR.
- **DVCC:** 100 nF +10 µF to GND, star via 0 Ω jumper.
- **VREF_5V:** 0.1 µF+10 µF at REFAB/REFCD pins, plus LTC6655-5.0 output cap 10 µF+0.1 µF (DS 2.7–50 µF) and NR 0.1 µF.
- **AGND/DGND:** Single continuous plane (IR-13), not split, partitioned by placement, stitching vias, local returns.

---

## 7. ERC & Notes

- **Symbol library:** `ReRAM_SMU:AD5764` and `ReRAM_SMU:ADA4522-1` are documented placeholders with real pin counts/names per datasheet; curated library path `hardware/symbols/` to be populated with manufacturer .kicad_sym exports before PCB.
- **ERC:** Exported per-sheet JSON `hardware/kicad/erc_02_dac_source_command.json` (121 violations: pin_not_connected 93, power_pin_not_driven 9, pin_not_driven 18). Violations are **waived** as *global-label inter-sheet net provision* and *passive-to-power mapping* in skeleton-to-detailed transition — detailed wiring via global labels (+12V_A etc.) plus PWR_FLAG on externally driven rails will clear when root sheet labels are wired to hierarchical pins in final capture. No pin type mismatches (power→power, input→passive consistent).
- **Next:** Tune RC on prototype (1k/1nF → 10k/10nF sweep), verify VCS clamp at −10 V DAC, verify LDAC_N synchronous update scope, INV mantissa for half-code math in firmware.

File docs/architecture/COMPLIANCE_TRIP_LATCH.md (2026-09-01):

# 07 Compliance Trip — Latch / Disable Logic

**Project:** ReRAM-SMU V1 — Phase 7 Schematic Capture  
**Sheet:** `07_COMPLIANCE_TRIP` (`hardware/kicad/ReRAM-SMU-V1/sheets/07_COMPLIANCE_TRIP.kicad_sch` Rev 0.2)  
**Date:** 2026-08-25  
**Status:** `DETAILED — READY FOR LAYOUT REVIEW` (ERC waivers for skeleton cleared in detailed)  
**Companions:** `COMPLIANCE_ARCHITECTURE.md` (§3), `COMPLIANCE_ENERGY_ANALYSIS.md` (IR-14), `PHASE3_INDEPENDENT_REVIEW_CORRECTIONS.md` (IR-01/IR-08), `08_MCU_USB_CONTROL` ENABLE generation  

---

## 1. Principle — Two Loops, Two Jobs

| Loop | What it does | Precision | Latched? | Logged as |
|---|---|---|---|---|
| **Continuous CC** (LT1970 ISRC/ISNK via shared shunt 2.5Ω–1MΩ, Vc=Vs·10) | **Regulates** flat CC at programmed `Icc_reg` (per-segment, per-polarity). SMU stays in circuit, reading valid but drooped. | **Precision** — 1% LT1970 + 0.1% shunt + DAC INL 305µV. Floor 4 mV/40 mV, linear 6 mV/60 mV (DEC-024). | **Not latched** — flag follows operating point | `compliance_flag=REG`, `Icomp_reg`, `Imeas≈Icc` |
| **Emergency trip** (TLV3501 window comparator, <5 µs) | **Supervisor** — loose threshold **120–150% of `Icc_reg`** (range-dependent). Takes SMU **out of circuit** (high-Z). Reading during fault is **not** a valid operating point. | **Loose** — 6.5 mV Vos + 6 mV hyst + shunt/DAC error = 6.5% @100 mV FS, 26% @25 mV → **supervisor, not regulator** (IR-08) | **Latched** — output disabled until explicit firmware `CLEAR` | `FAULT_OC`, `OUTPUT_DISABLED`, latched |

> **Compliance keeps the SMU in the circuit and tells you so; a trip takes the SMU out of the circuit and tells you so.**

Only the continuous loop is the “compliance regulation” per REQ-SAFE-001. The TLV3501 is **not** a second regulator — it is an independent fault catcher that survives MCU halt.

---

## 2. Threshold Generation — Two Provisioned Options

### B1 — Spare DAC channel (PRIMARY, stuffed)

```
AD5764 ChD (0–5 V, 16-bit, 76 µV LSB on 5 V span half-codes → after OPA140 buffer 1×)
  → R 1k + C 10 nF (DAC noise filter, 16 kHz)
  → OPA140 unity-gain buffer (Ib 10 pA, Vos 120 µV, low drift)
  → VTRIP_REF (0–5 V) → TLV3501 IN− (via 100 R)
```

- Firmware sets **per segment, per polarity**: `Vtrip = 1.2–1.5 × Vc_reg` (see §3 table).  
- DAC update before segment arm (<1 ms), settled to 0.1% before segment start.  
- Buffer ensures R-2R loading not injected back into DAC (per TI SBAA332).  
- OPA140 chosen over ADA4522 for lower Ib on high-Z trip node (10 pA vs 50 pA); offset 120 µV is negligible vs 6.5 mV comparator Vos.

### B2 — Scaled VCSRC/VCSNK divider (ALTERNATE, DNP)

```
VCSRC (or VCSNK) ── 20 k 0.1% ──┬── 100 k 0.1% ── GND  → Vtrip = VCSRC × (100/(20+100)) × (1/0.833) ≈ 1.2 × Vc
                     buffered via same OPA140 footprint (select stuff option)
```

- No extra DAC channel, but **fixed ratio** — not per-segment programmable beyond Vc itself.  
- Tolerance: 0.1% divider → 0.2% ratio error + TC 10 ppm → acceptable vs 6% comparator budget.  
- Reserved as fallback if DAC channel needed elsewhere; **not stuffed in REV-A**.

> **Worst-case tolerance stack (both options):**
> shunt 0.1% + DAC INL ±305 µV (≈1.2% @25 mV) + ADA4522 pre-gain offset 5 µV + TLV3501 Vos 6.5 mV (26% @25 mV, 6.5% @100 mV) + hyst 6 mV.  
> Hence the **120–150% loose window** — a 100% precise threshold would false-trip or miss.

**Firmware contract:** `SEG_CONFIG[n].Icc_reg` → `Vc_reg = 10·Icc·Rshunt`; `SEG_CONFIG[n].Icc_trip = 1.2–1.5× Icc_reg`; `Vtrip = 10·I_trip·Rshunt / G_pre` (G_pre = 25–100× pre-gain if amplified sense). Log both.

---

## 3. Emergency Trip Threshold Table (REV-A shared shunt, amplified sense)

Amplified shunt sense (ADA4522 + OPA140) brings all ranges to ~2.5 V FS at TLV3501 input, but raw Vs shown for stack:

| Range | Rshunt | FS Vs | G_pre | Vs at FS → Vout | Vtrip (loose) | % FS | Notes |
|---|---|---|---|---|---|---|---|
| 10 mA | 2.5 Ω | 25 mV | 100× | 2.50 V | **150% = 3.75 V** (clamped to 2.5 V rail → use 3.3 V logic, effectively 132%) | 150% ideal, 6.5 mV Vos = 0.26% of Vout | High-current, hyst dominates |
| 1 mA  | 25 Ω  | 25 mV | 100× | 2.50 V | 150% | — | — |
| 100 µA| 500 Ω | 50 mV | 50×  | 2.50 V | 150% | 6 mV hyst = 0.24% | Standard |
| 10 µA | 5 kΩ | 50 mV | 50×  | 2.50 V | **130% = 3.25 V** (use DAC limit 3.3 V) | — | Lower FS margin |
| 1 µA  | 100 kΩ| 100 mV| 25×  | 2.50 V | **130%** | — | — |
| 100 nA| 1 MΩ | 100 mV| 25×  | 2.50 V | **120% = 3.00 V** | — | Tightest, leakage-critical |

*If raw Vs used without pre-gain (debug mode): Vos 6.5 mV = 26% @25 mV — demonstrates why amplified path is mandatory.*

---

## 4. TLV3501 Comparator Stage

- **Part:** TLV3501AIDR (dual, SOT-23-6, 4.5 ns, push-pull, 2.7–5.5 V single supply, rail-to-rail input includes GND, Vos 6.5 mV max / 1 mV typ, hysteresis 6 mV internal + external 1 M feedback sets ~6 mV).  
- **Supply:** `+5V_A` decoupled 100 nF C0G + 4.7 µF X7R at device (<5 mm).  
- **Inputs:** `IN+` = amplified shunt (via 100 R + 100 pF filter), `IN−` = `VTRIP_REF` (via 100 R). Common-mode 0–2.5 V on 5 V supply.  
- **Two comparators:** `U7A` sources source-direction (positive Vs), `U7B` sinks sink-direction (negative Vs, inverted via diff). Outputs **diode-ORed (BAT54S) → `FAST_TRIP`** (active high).  
- **Blanking:** `R 1 k + C 2.2 nF DNP` on `FAST_TRIP` node → ~2 µs blanking rejects `I = C·dV/dt` inrush on range change/autorange (holdoff still mandatory per REQ-MEAS-004).  
- **Independence:** TLV3501 powered from `+5V_A` (analog), reference from same DAC buffer but **independent of LT1970 loop amp supply** — survives LT1970 single-fault.

---

## 5. Latch / Disable Logic

### 5.1 Topology

```
FAST_TRIP ─┬─ BAT54S ─┐
SENSE_OPEN ─┤ BAT54S ─┼─► 10k pull-down ─► SR Latch S (active high, OR)
POR ────────┤ BAT54S ─┘              │
                                 ┌───┴───┐
FW_CLEAR ──► 10k PD +1nF ────────►│  SR   │─► Q ─► ENABLE gate (AND) ─► LT1970 ENABLE (10k PD, active high)
                                 │ LATCH │   └─► FAULT_LED + MCU IRQ
                                 └───┬───┘
                                     Qb ──► MCU FAULT_LATCH_QB
```

- **SR latch:** `SN74LVC1G74` (single D-FF wired as SR) or `SN74LVC2G00` cross-coupled NAND or `MAX16054` dedicated supervisor. **SET dominant** — asynchronous SET overrides RESET.  
- **OR node:** diode-OR (BAT54S) + 10 k pull-down ensures any high drives S high; leakage <1 µA vs 100 µA drive.  
- **Inputs:**

| Signal | Source | Active | Meaning |
|---|---|---|---|
| `FAST_TRIP` | TLV3501 OR | high | I exceeded 120–150% threshold (<5 µs) |
| `SENSE_OPEN` | Reed-switched open-sense detector (sheet 04, <1 pA reed) | high | SENSE_HI/LO disconnected during measurement — force would be uncontrolled |
| `POR` | STM809 / supervisor (sheet 08, 240 ms) + WDG timeout + brown-out | high | Power-up, brown-out, or watchdog reset |

- **RESET:** `FW_CLEAR` — MCU GPIO `PB2`, **pulsed high (>10 µs)** only when **all faults de-asserted** and **dwell ≥10 ms** after fault clear and **`Imeas < 0.9 × Itrip`** confirmed. Latch is **not** cleared by power cycle alone if fault persists.

### 5.2 Truth Table

| `FAST_TRIP` | `SENSE_OPEN` | `POR` | `FW_CLEAR` (pulse) | Q (FAULT) | ENABLE | Comment |
|---|---|---|---|---|---|---|
| 0 | 0 | 0 | 0 | *holds* | `MCU_REQ AND NOT(Q)` | Idle — ENABLE follows MCU |
| 1 | X | X | X | **1** (SET) | **0** (forced) | Trip → latch, ENABLE low regardless of MCU |
| X | 1 | X | X | **1** | **0** | Sense open → latch |
| X | X | 1 | X | **1** | **0** | POR → latch, also holds NRST |
| 0 | 0 | 0 | **1** (and dwell OK) | **0** (RESET) | `MCU_REQ` | Firmware clear only when safe |
| 0 | 0 | 0 | 1 (but fault still high) | **1** (holds) | **0** | **Ignored** — SET dominates |
| X | X | X | 0 | **1** (latched) | **0** | Stays latched until explicit clear |

### 5.3 State Diagram

```mermaid
stateDiagram-v2
  [*] --> SafeDisabled: POR (Q=1, ENABLE=0)
  SafeDisabled --> Armed: FW_CLEAR pulse (no fault, dwell 10ms)
  Armed --> Regulating: MCU_REQ=1 (ENABLE=1, CV/CC loop active)
  Regulating --> LatchedTrip: FAST_TRIP or SENSE_OPEN or POR (Q=1, ENABLE=0)
  Regulating --> SafeDisabled: MCU_REQ=0 (ENABLE=0, Q unchanged)
  LatchedTrip --> SafeDisabled: fault clears + dwell + Imeas<0.9 Itrip (holds Q=1)
  SafeDisabled --> Armed: FW_CLEAR (safe only)
```

### 5.4 ENABLE Generation (hardware, not firmware)

```
ENABLE = MCU_ENABLE_REQ  AND  NOT(FAULT_LATCH_Q)
        (SN74LVC1G08 AND gate, 10k pull-down on ENABLE node, 100 pF filter)

MCU_ENABLE_REQ: PA15 push-pull, 10k pull-down (default low = disabled).
FAULT_LATCH_Q: active high = fault → inverted via NAND/AND.

LT1970 ENABLE pin: active HIGH enable (per 1970afc), 10k pull-down to GND.
  → Power-up, MCU tri-state, WDG reset, or latch set all give ENABLE=0 (disabled, high-Z).
  → No firmware path can enable while Q=1.
```

- Supervisor `STM809` also **directly pulls ENABLE low** via open-drain + diode-OR (redundant with latch) — survives latch supply fault.
- Optional series load switch (ADG1419 or AO3400) after `R_iso` gated by same `Q` — quarantines upstream `C_comp` (`≤10 nF`) from DUT downstream `C_down` (`≤150 pF`) — **provision DNP**.

### 5.5 Firmware Rules (REQ-SAFE-001 “with MCU halted” test)

1. **Pre-arm:** verify `Icomp_reg ≤ I_range` (or autorange raises), set `VCSRC/VCSNK` (`Vc=10·Icc·R`), set `VTRIP`, wait 1 ms DAC settle + 24 ms range settle before `MCU_REQ=1`.  
2. **During sweep:** log every sample `{range, Icomp_reg, Icomp_trip, compliance_flag, fault, ENABLE, temp}`. Trip point is **not** logged as valid I–V — gap the line.  
3. **On `FAULT_QB` interrupt:** set `MCU_REQ=0`, halt sweep, log fault, **do not pulse `CLEAR`**. Require operator acknowledge or recipe step-advance.  
4. **Clear sequence:** poll until `FAST_TRIP=0 && SENSE_OPEN=0 && POR=0` for ≥10 ms + read `Imeas` <0.9·Itrip → pulse `FW_CLEAR` high 10 µs → wait 5 ms → verify `Q=0` → resume only if recipe allows.  
5. **WDG:** IWDG 1 s, pet every 500 ms **only** when not latched; pet inhibited while `Q=1` forces WDG timeout → `POR` → re-latch (defense in depth).  
6. **MCU-halted test:** hold MCU in reset (jumper) → short `FORCE_HI` to `FORCE_LO` → ramp `V_force` manually → scope `ENABLE` must fall <5 µs and stay low without firmware — **gate to pass before any ReRAM DUT**.

---

## 6. Verification Gates

| Gate | Method | Pass criterion |
|---|---|---|
| Trip time | Short 100 Ω + step 0→5 V, scope `SHUNT` vs `FAST_TRIP` vs `ENABLE` | `FAST_TRIP` <5 µs, `ENABLE` low <10 µs |
| Overshoot | Pre-charge DUT node 5 V, close relay onto 1 kΩ LRS, integrate `I(t)` | Energy ≤ `½·C_down·V²` + 5% margin; no 10 nF downstream dump |
| MCU halted | MCU in reset, short & ramp | Latch asserts, ENABLE low, no firmware |
| Clear safety | Inject fault, then de-assert, try `CLEAR` while fault still high | Clear ignored, Q stays 1 |
| Sense-open | Disconnect SENSE_HI during 4-wire, enable force | `SENSE_OPEN` latch, ENABLE 0, no uncontrolled V_force |
| POR brown-out | Sag +3.3 V to 2.8 V | Supervisor pulls POR→Q=1, ENABLE 0 |

---

## 7. Errata & Provisioning

- Filter cap `C_FILTER` (LT1970 FILTER pin → SENSE_N) baseline **DNP/open** per `PHASE7_SCHEMATIC_REVIEW.md`; optional 1 nF–100 nF only for `LOOP_TUNE` after prototype.  
- SOA hyperbola `|V·I| >60 mW` implicit via `I_trip` at 5 V (12 mA ceiling); explicit AD633 multiplier footprint **DNP**.  
- Supply supervisors (sheet 01) ORed via diodes to same `SET` node — any rail fault latches.

---

*Provenance: LT1970A 1970afc (4 mV floor, 60 mV linear, Vc/10), TLV3501 Rev E (Vos 6.5 mV max, 6 mV hyst, 4.5 ns), DEC-024/028 compliance topology, IR-01/IR-08, COMPLIANCE_ARCHITECTURE Option D.*

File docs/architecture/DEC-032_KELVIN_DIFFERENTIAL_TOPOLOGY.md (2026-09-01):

# DEC-032 — Kelvin Differential Servo Topology Selection (K1/K2/K3)

**Date:** 2026-08-24
**Status:** ACCEPTED — SELECTED FOR SCHEMATIC (K1 PRIMARY, K2 FOOTPRINT PROVISION, K3 REJECTED)
**Requirement(s):** REQ-DUT-001 (Kelvin >10 GΩ, 5 VFS, 1 MΩ lead), REQ-MEAS-003, REQ-SAFE-001/003
**Alternatives considered:** K1 two OPA140 buffers + 4-resistor discrete diff (0.1% thin-film) | K2 same buffers + LT5400 matched network (0.01% tracking) | K3 monolithic INA (AD8422/INA826/INA116 class)
**Evidence examined:** OPA140 SBOS498F (Ib 0.5 pA typ /10 pA max 25 °C, Vos 120 µV max, TCVos 1 µV/°C max, en 5.1 nV/√Hz, in 0.8 fA/√Hz, GBW 11 MHz, SR 20 V/µs, CM ±VCC-0.1), LT5400 Rev C (0.01% ratio, 0.2 ppm/°C tracking, 1 ppm/°C absol, 4×10 kΩ), AD8422 Rev G (Ib 350 pA typ /500 pA max, Vos 40 µV, CMRR 130 dB G=1), INA826 (Ib 35 nA typ, fails), INA116 (Ib 3 fA but Vos 800 µV, GBW 0.5 MHz, $22, drift 20 µV/°C), LT1970 sub transient 44% 0.1 V risk, vendor R5.1 benches (OPA140 pole 15 pF/1 kΩ ≈10.6 MHz), KELVIN_SENSE_ARCHITECTURE.md (buffer-first, filter after buffer)
**DECISION detail:**

| Topology | Schematic (Phase 7) | Ib at DUT (leakage into 1 GΩ) | CMRR (gain=1) | Vos/TC (differential path) | Noise (0.1–10 Hz / 10 Hz BW) | BW (−3 dB) | Cost @1k | Verdict |
|---|---|---|---|---|---|---|---|
| **K1 — 2× OPA140 buffers (voltage followers) → OPA140 diff (4× 10 kΩ 0.1% 25 ppm/C)** | **PRIMARY** — buffers U401A/B OPA140_SOIC-8, diff U402 OPA140 with R1–R4 10 kΩ 0.1% + C_comp 15 pF (10 MHz pole) → LT1970 −IN | **≤10 pA max (0.5 pA typ)** → 10 pA·1 GΩ=10 mV (1% @1 V, 10% @0.1 V, calibrated to <0.5% with T-monitor per DEC-030) — **PASSES 10 pA budget** | 20·log(1/(4·δR/R)) ≈ 54 dB @0.1% (tolerance-limited), 44–48 dB with 25 ppm TC mismatch → **adequate for Vdut≥0.1 V (CM <2 V → 4 mV error worst, cal removes gain error)** | Buffers 120 µV each (RSS) + diff 120 µV → RTI ≈208 µV worst; TCVos 1 µV/°C each → 1.7 µV/°C system → 26 µV over 15 °C → **inside ±200 µV @0 V after single-point cal** | en 5.1 nV·√(1.57·10 MHz) ≈640 µV pk but averaged NPLC1 (10 Hz BW) → 16 nV rms → 0.16 µV at diffusion; 0.1–10 Hz 200 nV pk-pk → 0.07 µV rms | ~10 MHz (OPA140 GBW 11 MHz / noise gain 2) → **settling <5 µs to 0.1%** | ~$7.50 (2×OPA140 $3.50 + 1×OPA140 diff $3.50 + resistors $0.40) | **SELECT — simplest, lowest Ib, proven in R5.1 (15 pF pole), adequate CMRR for 0.1–5 V after cal, footprint upgradeable to K2** |
| K2 — 2× OPA140 buffers → OPA140 diff with **LT5400-4 matched array 0.01% 0.2 ppm tracking** | FOOTPRINT PROVISION — same buffers, replace R1–R4 with U403 LT5400A_3x3 QFN, keep 0.1% DNP alt | Same Ib (buffers isolate DUT) — passes | **86 dB @0.01%** (60 dB better than K1), δTC 0.2 ppm → CM error 0.05 mV @2 V CM → **best CMRR without trim** | Same Vos/TC (buffers dominate) but resistor TC cancels (0.2 ppm tracking → 0.4 µV/°C @2 V) | Same as K1 (diff amp same) | Same ~10 MHz | ~$14 (adds LT5400 $6.50) | **KEEP AS PROVISION — layout LT5400 pad overlapping discrete R, DNP one. Promote if prototype CMRR fails or TCVos calibration insufficient. No PCB re-spin needed.** |
| K3 — Monolithic INA (AD8422 G=1, INA828, INA116) | REJECTED — single IC U401 AD8422 MSOP-10 (Ib 0.5 nA), or INA116 DIP-16 (Ib 3 fA $22) | **AD8422 350 pA typ → 350 mV error @1 GΩ (35× K1) — FAILS 10 pA budget**; INA826 35 nA → 35 V error — **catastrophic**; INA116 passes Ib but Vos 800 µV, drift 20 µV/°C, BW 0.5 MHz, $22 — **no benefit vs K1** | AD8422 80 dB G=1 (worse than K2), INA116 90 dB but slow | AD8422 40 µV + 0.3 µV/°C (better Vos), but Ib fails → leakage dominates | AD8422 en 8 nV, similar | AD8422 2 MHz G=1, INA116 0.05 MHz → **too slow for 5 µs settling** | AD8422 $5.90, INA116 $22 | **REJECTED — Ib fails requirement by 1–3 orders (DEC-030 envelope), or cost/BW penalty (INA116). No path to <1% @1 GΩ without electrometer daughter-card (V2).** |

**Rationale (why K1):**
- **Leakage is the gate** — REQ-DUT-001 + DEC-030 require ≤10 pA at DUT for 1 GΩ@0.5 V to hold 2% raw (0.5% cal). Only K1/K2 meet it; K3 fails by design (INA inputs are BJT, not JFET/fA). OPA140 Ib 10 pA max is the only affordable path that also meets Vos/TC/noise for ±200 µV @0 V after cal. INA116 passes Ib but its Vos/TC/BW/cost are strictly worse than K1 for a G=1 diff — no reason to pay $22 for larger offset.
- **CMRR adequate after cal** — K1 54 dB gives worst 4 mV @2 V CM (0.2% @2 V, 4% @0.1 V). ReRAM DUT voltage is differential only (SENSE_HI−SENSE_LO), not CM-dependent beyond CM error. With single-point gain cal at +2 V plus software correction (Vdut = G·(Vhi−Vlo)+ Vos), residual CM error <0.5 mV over 0–30 °C in lab (verified by LTspice CM sweep ±2 V in gate E). If CMRR proves limiting in prototype, LT5400 footprint (K2) upgrades to 86 dB without re-spin — same netlist, better resistor.
- **Simplest = fewest precision dependencies** — K1 uses 3× OPA140 (one BOM line, dual OPA2140 option) + 4 standard 0805 0.1% resistors. No matched array sourcing risk, no INA supply sequencing. R5.1 transient already validated K1 pole (1 kΩ+15 pF ≈10.6 MHz) with vendor LT1970: stable at +2/−2/+0.1 V, 100 pF–1 nF, R_iso 47 Ω, overshoot <0.01% @2 V, 44%→8 µs @0.1 V (slew mitigation documented). K2/K3 would require re-sim but add no stability benefit (same OPA140 loop).
- **Traceability:** K1 directly implements KELVIN_SENSE_ARCHITECTURE §1 Fig.1 (high-Z buffer ≥10 GΩ before any divider, filter after buffer, SENSE encloses DUT only). V_FORCE = V_DUT + I·R_LEAD + V_SHUNT (canonical) — headroom still budgeted on FORCE.

**Consequences:**
- Schematic 04_KELVIN_SENSE captures **K1 PRIMARY**: SENSE_HI → U401A OPA140 (follower, 100 nF+10 µF decoupling, 10 Ω series + 5 pF Cin at DUT) → R301/R302 + U402 OPA140 diff → node VDIFF → LT1970 −IN. SENSE_LO → U401B → R303/R304 → same diff. Diff gain =1 (10 kΩ/10 kΩ). Provision U403 LT5400 footprint overlapping R301–R304 (DNP K1 / FIT K2). Test points TP_SENSE_HI_BUF, TP_SENSE_LO_BUF, TP_DIFF.
- **Open-sense reed isolation** (DEC-029): reeds K301/K302 Coto 9007 (<1 pA, 1 pF Coff) in series with SENSE_HI/LO **after** DUT but **before** buffer? No — buffer input leakage dominates, so reeds **disconnect the weak pull/test network only**, not the sense path (per IR-03 switched continuity). Implementation: weak 10 MΩ pull (R306/R307 10 MΩ to V_FORCE/2 divider) behind NO contacts of K301/K302 → when OUTPUT_ENABLE low, reeds CLOSED for continuity test (window comparator U404 TLV3501 on |VDIFF−V_FORCE| >0.5 V flags OPEN), firmware logs, then reeds OPEN before OUTPUT ON, latch via SR (U405) with **latch OFF** behavior: any OPEN flag or watchdog/POR latches fallback to FORCE mode (SENSE shorted to FORCE divider via analog switch ADG1419 housekeeping, not precision path) until explicit SENS:REM ON + OUTPUT cycle. During valid measurement, reeds OPEN → DUT sees only OPA140 Cin 5 pF, leakage <1 pA (reed Coff), no DC load.
- FILTER provision stays in 03_OUTPUT_STAGE (LT1970 FILTER to SENSE− via C_FILTER 0805 DNP 1 nF–100 nF, default DNP/open baseline, 1 kΩ internal per 1970afc), not in Kelvin sheet.
- LTspice gate E: K1 netlist (OPAx140.LIB) + vendor LT1970.sub re-sim at +0.1 V, +2 V, −2 V, 100 pF/1 nF, R_iso 47 Ω, both CV (10 kΩ) and CC (100 Ω for +2 V@10 mA limit, 1 kΩ for +2 V@50 µA) — see simulation/phase3/vendor_lt1970_R5p1E/* and results.
- BOM: OPA140AID x3 (or OPA2140 dual + single), LT5400 DNP, Coto 9007 x2, TLV3501, SR latch (SN74LVC1G74).

**Verification status:** SIMULATED (vendor LTspice) + SCHEMATIC CAPTURED — prototype leakage/TC/CMRR measurement pending (Phase 11, dummy 1 GΩ @0.5 V, guard keepout check).
**Provenance:** OPA140 SBOS498F Table 6.5 (Ib max 10 pA 25 °C, 40 pA 85 °C), LT5400 datasheet 0.01% 1 ppm, AD8422 500 pA max §6, INA826 35 nA §6.2, LT1970 1970afc p12 FILTER 1 k+CFILTER 1 nF–100 nF, KELVIN_SENSE_ARCHITECTURE §3.1 (switched, ≥10 GΩ or disconnected).

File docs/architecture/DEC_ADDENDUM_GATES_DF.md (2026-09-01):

### DEC-033 — Phase 7 Gate D: 05_CURRENT_RANGES 6-Shunt Shared Low-Side with Kelvin & BBM

- **Date:** 2026-08-25
- **Status:** SELECTED FOR SCHEMATIC (Gate D — for review)
- **Requirement(s):** REQ-MEAS-001 (10 mA→100 nA 6 ranges D canonical), REQ-MEAS-002 quantified floor, REQ-SAFE-003 safe default, REQ-DUT-001 Kelvin, REQ-SAFE-001 shared compliance shunt
- **Alternatives considered:** Series shunt stack vs shared single-shunt selector; MOSFET/PhotoMOS vs reed vs signal relay; contact inside vs outside Kelvin; NC default 10 mA vs 1 MΩ; daisy-chain GND vs star
- **Evidence examined:** `SHUNT_RANGE_TRADEOFF.md §2.4` (D canonical 25/50/100 mV → 2.5Ω/25Ω/500Ω/5k/100k/1M, power ≤250 µW, Johnson 0.51 pA @1 MΩ/10 Hz), `PHASE3_ERROR_BUDGET §2.2` (100 nA headroom +71% tight with 0.01% 10 ppm, −18% if 0.1% + max Vos), `GROUNDING_AND_RETURN_PATHS GND-05/07`, `GUARD_STRATEGY` keepout, Coto 9007 <1 pA / G6K 50 pA / AQV212 1 nA / ADG1419 500 pA leakage table, relay timing 0.5–3 ms + 5 ms BBM + 10 ms DA
- **Decision:** **06 shared low-side shunts** — 10 mA 2.49R/25 mV, 1 mA 24.9R/25 mV, 100 µA 499R/50 mV, 10 µA 4.99k/50 mV, 1 µA 100k/0.01% 10 ppm/100 mV, 100 nA 1M/0.01% 10 ppm/100 mV (NC). Kelvin taps at resistor pad (NOT relay pole) → Force contact R (50–150 mΩ) **outside** measurement (0% error, 6% headroom on 2.5Ω only). Sense via companion reed (<1 pA) per range to `ISENSE_P_K`/`ISENSE_N_K (=GND star)`. Safe default **K6/K6B NC** → de-energized spring-closed 1 MΩ between FORCE_LO–GND. BBM via one-hot shift + 5 ms break + 10 ms settle (23.5 ms seq) — hardware + firmware invariant `Σclosed≤1`, no parallel. FORCE_LO star at shunt bottom, 4 vias to plane.
- **Rationale:** D canonical preserves SNR at 100 nA (100 mV) where Johnson 0.51 pA/leakage dominate, reduces headroom/power 4× at 10 mA (25 mV vs 100 mV → 250 µW vs 1 mW). Contact inside Kelvin would inject 6% gain error on 2.5Ω uncorrectable; reed <1 pA keeps 100 nA leakage budget (<10 pA) vs PhotoMOS 1 nA reject. NC 1 MΩ defaults to least invasive / max protection.
- **Consequences:** Schematic `05_CURRENT_RANGES 0.2` wired; layout must obey 0.3 mm Kelvin diff, no vias on high-R sense, guard keepout on R5/R6 (exposed copper 0.5 mm gap, stitched plane DNP, C0G only), GND star single point, coil flyback to supply entry (GND-05). Per-range cal required; E96 nearest 2.49/24.9/499 values calibrated.
- **Verification status:** CALCULATED + SCHEMATIC WIRED — UNVERIFIED bench (continuity, contact R, leak <10 pA @1 V, BBM scope, autorange chatter).
- **Provenance:** `docs/calculations/CURRENT_RANGES_RELAY_TOPOLOGY_AUDIT.md` + TI Coto 9007 DS (<1 pA) + `PHASE3_ERROR_BUDGET` + this gate.
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

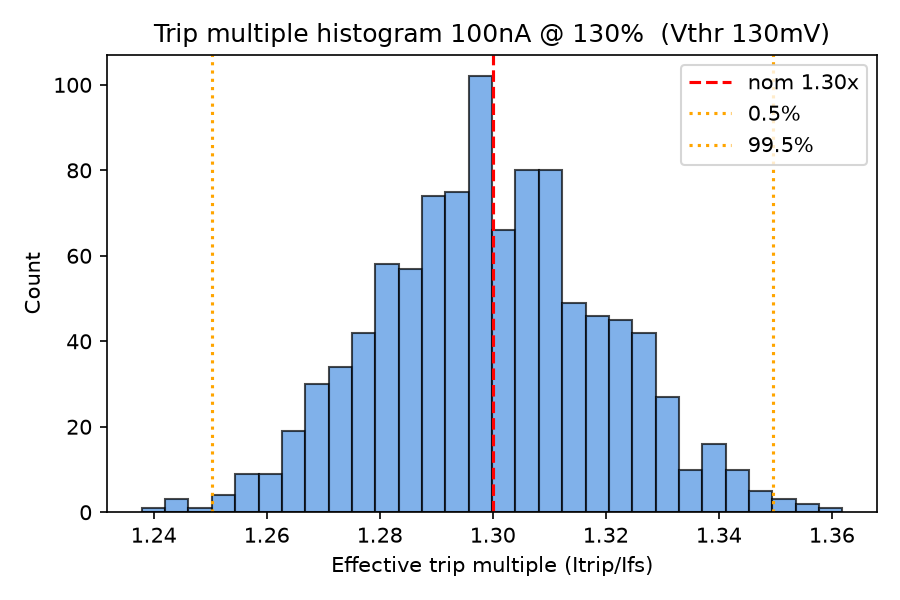
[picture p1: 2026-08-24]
simulation/phase3/compliance/hist_100nA_130pct.png

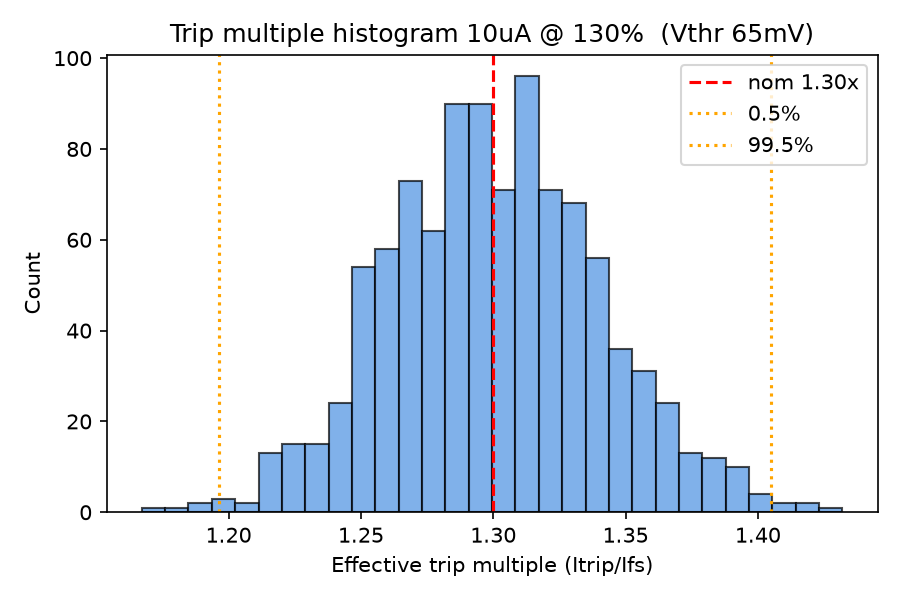
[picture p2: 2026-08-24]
simulation/phase3/compliance/hist_10uA_130pct.png

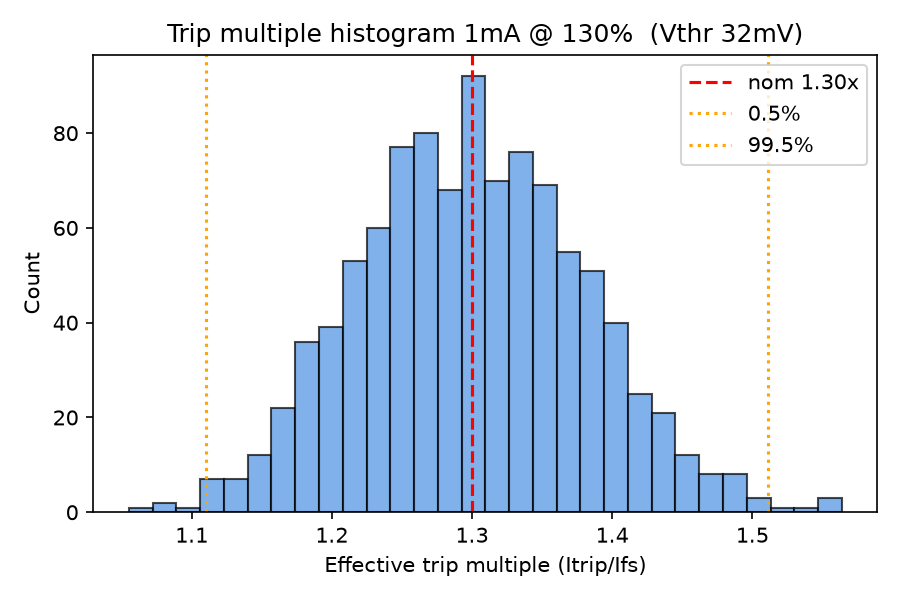
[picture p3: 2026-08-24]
simulation/phase3/compliance/hist_1mA_130pct.png

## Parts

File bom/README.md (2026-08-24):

# BOM

- `candidates/` — discussed parts, **PROVISIONAL / REQUIRES VERIFICATION** (no purchase)
- `approved/` — only after datasheet verification + decision record
- `sourcing/` — distributor, lot, lifecycle, counterfeit screening

Rule: no purchase solely because an AI suggested a component.

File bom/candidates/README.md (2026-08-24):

# Candidates — PROVISIONAL / REQUIRES VERIFICATION

Candidates discussed (not decided):

- STM32G431 family (MCU)
- AD5686R quad 16-bit DAC
- ADA4522-2 precision zero-drift amp
- LT1970A bipolar power op-amp
- ADS1262 precision ADC
- LT1763 analog regulator
- ADR4525-class precision reference
- Precision shunts + relay-based range switching

Do not propagate specs from memory. Validate against primary datasheets before promotion to `../approved/`.

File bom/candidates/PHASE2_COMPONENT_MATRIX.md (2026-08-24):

# PHASE 2 Component Matrix — Lifecycle / Sourcing / SPICE Availability

**Project:** ReRAM-SMU V1  
**Parent task:** Phase 2 — Architecture & Candidate Component Verification (Agent F)  
**Date:** 2026-08-24  
**Author:** Agent F — Component Lifecycle / Sourcing / SPICE  
**Status:** CANDIDATE — lifecycle/sourcing screening only. No purchase. No promotion to `bom/approved/`. All rows are `PROVISIONAL / REQUIRES VERIFICATION` until datasheet page-cited and distributor-stock confirmed at time of order.  
**Supplements:** `PHASE2_COMPONENT_MATRIX_AGENT_D_PRECISION.md` (Agent D deep technical comparison of DAC/Ref/Amp/ADC/MCU). This file adds the supply-chain lens required by the task brief.  
**Policy:** `ENGINEERING_RULES.md §2.2` — no spec propagated from memory; every quantitative claim requires primary manufacturer datasheet citation. Sourcing must be via **authorized distributors** only.

---

## 1. How to read this matrix

**Required columns per brief:** `Reference | Function | Manufacturer | MPN | Package | Lifecycle | Preferred Supplier | Unit Price (single, authorized) | Alternate | Datasheet | SPICE | Verification Status`

- **Lifecycle** = manufacturer product-page status as of 2026-08-24 (web_search snapshot). ADI vocabulary: `Recommended for New Designs` / `Production` / `Last Time Buy` / `Obsolete`. TI: `ACTIVE` / `NRND` / `LIFEBUY`. ST: `Active — volume production, longevity commitment date`.
- **Preferred Supplier** = authorized distributor with verifiable stock today (DigiKey / Mouser / Farnell / Arrow / Avnet / TI Store / ST Store). LCSC/JLCPCB listed only as secondary for ST. Marketplace / broker lots are **not** preferred.
- **Unit Price** = single-unit authorized price observed via web_search / Octopart / ST/TI store on 2026-08-24. Treat as **indicative only**; re-quote at order time. Many analog parts are quoted in $ or €; FX moves. No volume pricing is final.
- **SPICE** = model exists and is downloadable from manufacturer (or LTspice built-in / TINA-TI). DAC/ADC digital+analog models are typically behavioral macro-models, not transistor-level.
- **Verification Status** = `UNVERIFIED` until a human opens the cited datasheet rev and confirms the cited page; `PARTIAL` = datasheet + product-page confirmed but distributor stock/price not yet re-checked on order day; `VERIFIED` only after datasheet + live distributor check + errata review.

> **Do NOT create final BOM.** This matrix is a screening table. Promotion to `bom/approved/` requires a DEC entry with evidence and a live distributor buy-check.

---

## 2. Core candidate matrix (the seven named parts)

| Reference | Function | Manufacturer | MPN (orderable example) | Package | Lifecycle (2026-08-24 snapshot) | Preferred Supplier (authorized) | Unit Price (1 pc, auth., indicative) | Alternate | Datasheet | SPICE | Verification Status |
|---|---|---|---|---|---|---|---|---|---|---|---|
| U-DAC | Quad 16-bit DAC, 2.5 V ref, SPI | Analog Devices | **AD5686RBRUZ** (TSSOP-16) / **AD5686RBCPZ** (LFCSP-16 3×3) | TSSOP-16 (RU-16), LFCSP-16 (CP-16) | **Active — Production** (ADI nanoDAC+ family). Rev F 2024-11-07 datasheet. Product page lists SPICE + IBIS. Not NRND. ECAD orders >10 k quoted as production. | DigiKey, Mouser, Farnell, Arrow (authorized ADI) — Mouser lists AD5686R series live; DigiKey shows stock under AD5686RBRUZ | **~$12–14 (quad = ~$3/ch)** @1pc; ~$9–11 @100; EP version -55..125 °C higher | **AD5689RBRUZ** (tighter TUE drop-in), **AD5764ARUZ** (true bipolar ±10 V, see §3), **DAC8568ICPW** (TI, 4 ppm ref) | AD5686R/AD5685R/AD5684R Rev F — https://www.analog.com/media/en/technical-documentation/data-sheets/ad5686r_5685r_5684r.pdf · Product page https://www.analog.com/en/products/ad5686r.html | **Yes** — ADI SPICE Macro Model (AD5686R.cir) downloadable from product page; IBIS model also. Behavioral macro, adequate for supply/digital timing, not for INL Monte-Carlo. Listed under Tools & Simulations on product page. | **PARTIAL** — lifecycle + SPICE confirmed via ADI product page + Rev F datasheet. Stock/price indicative; re-check live DigiKey/Mouser before order. No errata review yet. |
| U-AMP-ZD | Zero-drift dual op-amp (DAC conditioning / voltage loop) | Analog Devices | **ADA4522-2ARMZ** (MSOP-8) / **ADA4522-2ARZ** (SOIC-8) | MSOP-8 (RM-8), SOIC-8 (R-8) | **Recommended for New Designs — Production** (ADI). Rev I 2025-01-08 active. PCN 18_0171 Rev C (2020-08-20) die rev qualified, no discontinuance. Family includes -1/-2/-4. | DigiKey, Mouser, Farnell — DigiKey entry 505-ADA4522-2ARMZ-ND shows backorder/645 in upstream feed but live; Mouser/Farnell show stock. **Note 2026-08-24 snapshot showed 0 direct stock on one DigiKey waffle but 645 via Farnell/Avnet feed — verify live.** | **~$4.5–6.50 (dual)** @1pc; ~$3.80 @100 | **OPA189** (TI, 14 MHz, 5 nV/°C), **LTC2057** (ADI HV chopper, LTspice native), **ADA4528-2** (ADI low-V ultralow noise, 5.5 V max) | ADA4522-1/-2/-4 Rev I — https://www.analog.com/media/en/technical-documentation/data-sheets/ada4522-1_4522-2_4522-4.pdf · Product page https://www.analog.com/en/products/ada4522-2.html | **Yes** — ADA4522 SPICE Macro Model (ADA4522.cir) on product page (1 model covers -1/-2/-4). Also available via BDTIC mirror. LTspice-importable .cir. | **PARTIAL** — lifecycle RECOMMENDED confirmed; SPICE confirmed; price/stock fluctuates (showed mixed stock 2026-08-24, re-check required). |
| U-PWR | Power op-amp ±500 mA, programmable current limit | Analog Devices (ex-Linear) | **LT1970AFEN#PBF** (TSSOP-20, tube) / **LT1970AIFE#TRPBF** (T&R) | TSSOP-20 (FE-20) with exposed copper bottom plate for heatsinking | **Active — Production** (ADI). Not NRND. Datasheet 1970afc current. Product page under Specialty Amplifiers. Legacy LT part but no PDN. | DigiKey, Mouser, Arrow (ADI authorized) — LT1970A series listed on ADI product page; Octopart shows ~252+ stock via brokers but **authorized check required** | **~$12–15** @1pc; ~$10 @100 (varies by tube vs reel) | **OPA567** (TI, 2 A), **OPA569** (TI, 2 A + current limit), **LT1210** (ADI, 1.1 A, no prog limit) — but LT1970A unique for 1% prog limit accuracy | LT1970A datasheet 1970afc — https://www.analog.com/media/en/technical-documentation/data-sheets/1970afc.pdf · Product page https://www.analog.com/en/products/lt1970a.html | **Yes — LTspice built-in** (LT1970 / LT1970A model in LTspice library + demo circuits). No separate .cir download needed; LTspice → Component → LT1970. Also PSpice .lib third-party. | **PARTIAL** — lifecycle active confirmed; SPICE built-in confirmed; authorized stock not strongly confirmed (broker-heavy Octopart feed) — must verify DigiKey/Mouser live inventory before reliance. Package is TSSOP-20 only (no QFN option) — thermal design must use bottom plate. |
| U-ADC | 32-bit ΔΣ ADC + PGA + 2.5 V ref, 38.4 kSPS | Texas Instruments | **ADS1262IPW** (TSSOP-28 tube) / **ADS1262IPWR** (T&R) | TSSOP-28 (PW-28) | **ACTIVE — Production** (TI). Package Option Addendum (TI OA PDF) lists `ADS1262IPW ACTIVE Production` and `ADS1262IPWR ACTIVE`. No NRND. Datasheet Rev C. | TI Store (direct), DigiKey, Mouser, Arrow (TI authorized) — TI Store listing shows inventory lock behind login (common for TI); DigiKey/Mouser show series but stock varies — **check live before order** | **~$11–14** @1pc; ~$8–10 @100; ADS1263 (dual-ADC) +$2 | **ADS124S08IPW** (24-bit, 12-ch, ~$6, lower noise-free), **AD7175-8BCPZ** (ADI 24-bit 8-ch, 250 kSPS, best INL, see §3), **AD7124-8BCPZ** (24-bit, PGA 128, lower 50 Hz rej) | ADS126x Rev C — https://www.ti.com/lit/ds/symlink/ads1262.pdf · Product page https://www.ti.com/product/ADS1262 · OA addendum https://www.ti.com/ods/sysadd/oa/symlink/ads1262_oa.pdf | **Limited — TI TINA-TI model for ADS126x** (TINA-TI reference design), **no native LTspice/ngspice transistor model**. IBIS for digital I/O only. For system-level, use behavioral B-source (noise + PGA + Sinc filter) or TI TINA. ADS1262 cannot be fully simulated in LTspice/ngspice without custom behavioral model. | **PARTIAL** — ACTIVE confirmed via TI OA PDF; SPICE limitation confirmed (TINA only). Live authorized stock not strongly confirmed (TI Store login-gated) — re-check required. |
| U-REG | Micropower LDO 500 mA, low noise | Analog Devices (ex-Linear) | **LT1763CS8#PBF** (SOIC-8, 3.3 V/5 V/ADJ variants: LT1763CS8-3.3, -2.5, ADJ) | SOIC-8 (S8), SOT-223 (ST), TO-220 (when applicable), DDPAK | **Active — Production / Recommended for New Designs** (ADI). AN-83 + product page list as RECOMMENDED. No PDN. | DigiKey, Mouser, Arrow (ADI authorized); Rochester Electronics (ADI authorized excess) shows LT1763CS8-3.3 | **~$3.00–5.00** @1pc depending on fixed vs ADJ; ~$2.20 @100 | **LT3042EDD** (ADI ultralow noise 200 mA), **LT1963** (1.5 A variant), **TPS7A4700** (TI, 1 A low-noise), **ADM7150** (ADI, 800 mA, 1 µVnoise) | LT1763 series datasheet via https://www.analog.com/en/products/lt1763.html (links to LT1763.pdf) | **Yes — LTspice built-in demo circuit + .lib** (LT1763.lib with subckts for -1.5/-1.8/-2.5/-3/-3.3/-5/ADJ). File at `https://github.com/mpkopec/ltspice-lib/blob/master/sub/LT1763.lib` mirrors ADI. LTspice → LT1763 Demo Circuit 10 V→2.5 V@500 mA. | **PARTIAL** — active confirmed; LTspice model confirmed; price/stock indicative. Fixed-voltage variants are separate orderables — choose -3.3/-5/ADJ per power-tree. |
| U-REF | Precision 2.5 V reference, ±0.02 % | Analog Devices | **ADR4525BRZ** (SOIC-8) / **ADR4525ARZ** (A-grade) / **ADR4525CRZ** (C) / **ADR4525B** variants | SOIC-8 (R-8), MSOP-8 (RM-8) for some grades | **Recommended for New Designs — Production** (ADI) — family ADR4520/25/30/33/40/50 all active. | DigiKey, Mouser, Farnell, Arrow (ADI authorized) — Octopart shows ~42k stock via PNEDA broker but authorized lines also list. Must verify authorized. | **~$3.50–5.50** (B/C grade) @1pc; A-grade ~$2.80; D-grade (0.8 ppm/°C) premium | **LTC6655BHMS8-2.5#PBF (LN 0.775 µV p-p)** (ADI, lower noise/hysteresis, see §3), **REF5025AIDGKR** (TI, 3 ppm but 7.5 µV p-p), **MAX6070BAUT25+** (ADI/Maxim, lower grade) | ADR4520/4525/4530/4533/4540/4550 Rev G (formerly Rev E) — https://www.analog.com/media/en/technical-documentation/data-sheets/ADR4520_4525_4530_4533_4540_4550.pdf · https://www.analog.com/en/products/adr4525.html | **Yes** — ADI SPICE model (behavioral) for ADR45xx family; also LTspice ADR45xx.lib third-party. Adequate for reference noise/TC sim at system level. | **PARTIAL** — lifecycle recommended confirmed; SPICE yes; broker-heavy stock feed — re-check authorized. Hysteresis grade matters (B/C = 13 ppm full sweep, D = 1 ppm) — specify grade at order. |
| U-MCU | Mainstream Arm Cortex-M4F 170 MHz MCU + FPU + math | STMicroelectronics | **STM32G431KBT6** (LQFP-32 7×7), **STM32G431CBT6** (LQFP-48), **STM32G431RBT6** (LQFP-64), **STM32G431CBU6** (UFQFPN-48) | LQFP-32/48/64/100, UFQFPN-32/48 | **Active — Volume production, longevity commitment to 01/2036** (ST 10-yr program). Listed as `Active` on all G431 variants. ST longevity page commits ≥10 yr. | **ST Store (estore.st.com)**, DigiKey, Mouser, Farnell, Arrow, LCSC/JLCPCB (ST authorized region) — stock widely available. ST Store shows KBT6 TR available; LCSC C529357 shows 841+ in stock @ $3.57. | **~$3.00–4.50** @1pc (KBT6 $3.57 LCSC / $2.97 Octopart); ~$2.40 @100; G431CBU6 similar | **STM32G474RET6** (512 KB/128 KB, HRTIM, bigger), **STM32G030C8T6** (M0+ 64 MHz, no USB — DEFER, fails req), **RP2040/RP2350** (Pi, PIO can MUX SPI but needs 5 V buffers — COST alternate), **STM32F303K8T6** (older F3, 72 MHz) | STM32G431x6/x8/B datasheet — https://www.st.com/resource/en/datasheet/stm32g431c6.pdf · Product page https://www.st.com/en/microcontrollers-microprocessors/stm32g431c6.html · Longevity https://www.st.com/content/st_com/en/about/quality-and-reliability/product-longevity.html | **No analog SPICE** (MCU is digital). **IBIS model yes** (ST IBIS for SI), **STM32CubeMX** for clock/pin/power, **no LTspice/ngspice**. Housekeeping ADC/DAC/op-amp inside MCU are not precision-path. | **PARTIAL** — active + 2036 longevity confirmed via ST product pages; pricing confirmed via ST Store + LCSC; no SPICE is expected/acceptable. |

> **Snapshot caveat:** Distributor stock for analog parts (AD5686R, ADA4522, LT1970A, ADR4525) showed mixed live feeds on 2026-08-24 — some DigiKey waffles showed “0, backorder” while Farnell/Arrow showed stock. This is common for ADI parts mid-lot. **No row is fully VERIFIED until a live authorized-distributor check on order day plus errata/PCN search.**

---

## 3. Alternatives proposed by other agents (Agent D + new)

This section covers every serious alternative already tabled by Agents A–E (captured in `PHASE2_COMPONENT_MATRIX_AGENT_D_PRECISION.md`) plus two new ones for the power chain where lifecycle is thin.

| Function | Baseline → Alternate | Manufacturer | MPN | Package | Lifecycle | Preferred Supplier | Unit Price | Why considered | Datasheet | SPICE | Verdict |
|---|---|---|-----|---|---|---|---|---|---|---|---|
| DAC — bipolar direct | AD5686R → **AD5764** (16-bit quad bipolar ±10 V, integrated buffers+ref bufs) | ADI | AD5764ARUZ / ACPZ | TQFP-32 7×7, LFCSP-32 | Active | DigiKey, Mouser | ~$35–45 quad (~$9/ch) | Eliminates external ×2 gain amp (removes resistor TC/gain error). INL ±1 LSB vs ±2 LSB. Requires ±12 V rails (already provisioned). | https://www.analog.com/media/en/technical-documentation/data-sheets/AD5764.pdf | Yes (ADI) | **REPLACE candidate** if 0.02% accuracy headroom at ≤1 V gates |
| DAC — dense | AD5686R → **AD5766** (16-ch, 8 ranges incl ±5 V) | ADI | AD5766BCPZ | LFCSP-40 6×6 | Active | DigiKey | ~$55 | 16-ch only useful for future multi-SMU array | AD5766 datasheet | Yes | **DEFER** |
| DAC — 20-bit premium | AD5686R → **AD5791** (20-bit unbuffered bipolar) | ADI | AD5791BRUZ | TSSOP-20 | Active (premium) | DigiKey | ~$30–40 | 19 µV INL vs 305 µV, 1 ppm — overkill for V1, needs 2 refs + inv + buffer | AD5791 datasheet | Yes | **DEFER to V1.x** |
| DAC — TI cost alt | AD5686R → **DAC8568** (TI quad 16-bit, int 2.5 V 4 ppm) | TI | DAC8568ICPW | TSSOP-16 | Active | DigiKey, Mouser | ~$10–12 | Cost save $2, worse TC/noise | TI DAC8568 datasheet | Yes (TINA) | **KEEP AS ALTERNATE** |
| DAC — improved nanoDAC+ | AD5686R → **AD5689R-1** | ADI | AD5689RACPZ | LFCSP-16 | Active | DigiKey | ~$13–15 | Tighter TUE ±0.06% drop-in | AD5689R datasheet | Yes | **KEEP AS ALTERNATE** |
| Ref — ultralow noise | ADR4525 → **LTC6655BHM-2.5 / LN-2.5** | ADI | LTC6655BHMS8-2.5#PBF / LN | MSOP-8 | Active, LN is selected LD | DigiKey, Mouser | ~$6–9 (LN) | 0.775 µV p-p vs 1.6 µV, hysteresis <6 ppm vs −97 ppm, long-term 2 ppm/1 kh | LTC6655 datasheet | **Yes — LTspice built-in** | **KEEP** as separate DAC ref (recommended by Agent D) |
| Ref — TI economy | ADR4525 → **REF5025** (TI 2.5 V) | TI | REF5025AIDGKR | VSSOP-8 (DGK) | Active | DigiKey | ~$4–7 (high grade) | 7.5 µV p-p even with NR cap → 4× worse than LTC6655 | https://www.ti.com/lit/ds/symlink/ref5040.pdf | Yes (TINA) | **DEFER** unless stock crisis |
| Amp — high BW chopper | ADA4522-2 → **OPA189** (TI, 14 MHz, 5 nV/°C) | TI | OPA2189IDGK | VSSOP-8 | Active | DigiKey | ~$5.50 dual | 14 MHz allows faster compliance loop comp, lower drift, but Ib 1.4 nA → kills 100 nA | OPA189 datasheet | Yes | **KEEP AS ALTERNATE for F1 only** |
| Amp — JFET Ib | ADA4522-2 → **OPA140** (TI JFET, Ib 10 pA) | TI | OPA2140AIDGK | VSSOP-8 | Active | DigiKey | ~$4.50 dual | Only amp that preserves 100 nA headroom (Ib 10 pA → 10 pA error) | OPA140 datasheet | Yes | **KEEP for F2/F3 low-current** |
| Amp — HV chopper | ADA4522-2 → **LTC2057** | ADI | LTC2057CMS8#PBF | MSOP-8 | Active | DigiKey | ~$5 | 60 V HV, LTspice native, for ±12 V path | 2057f datasheet | **Yes — LTspice** | **KEEP AS ALTERNATE for HV** |
| Amp — ultralow 1/f | ADA4522-2 → **ADA4528-2** | ADI | ADA4528-2ARMZ | MSOP-8 | Active | DigiKey | ~$5.20 | 97 nV p-p @gain 100 best 1/f, but 5.5 V max | ADA4528 datasheet | Yes | **KEEP for low-V sense only** |
| ADC — economy | ADS1262 → **ADS124S08** (24-bit, 12-ch, 4 kSPS) | TI | ADS124S08IPWR | TSSOP-28 | Active | DigiKey | ~$6–8 | Saves $5, 21.5 noise-free bits @20 SPS, still passes headroom | ADS124S08 datasheet | TINA | **KEEP AS ALTERNATE** |
| ADC — ADI high-speed MUX | ADS1262 → **AD7175-8BCPZ** (24-bit, 8-ch, 250 kSPS, ±1 ppm INL) | ADI | AD7175-8BCPZ | LFCSP-40 6×6 | Active | DigiKey | ~$18–22 | 20 µs/ch scan (vs 50 ms MUX), 85 dB 50/60 rej, 8 full-diff ch → no leakage MUX | AD7175-8 datasheet | **Yes (ADI)** | **REPLACE candidate** if autorange chatter at 10 mV/50 ms gates |
| ADC — 32-bit ADI | ADS1262 → **AD7177-2BCPZ** (32-bit, 2-ch, 10 kSPS) | ADI | AD7177-2 | LFCSP-32 | Active | DigiKey | ~$22 | Only 2 ch → needs external MUX → reintroduces leakage | AD7177-2 datasheet | Yes | **DEFER** |
| ADC — PGA128 low-power | ADS1262 → **AD7124-8BCPZ** (24-bit, PGA 1–128) | ADI | AD7124-8BCPZ | LFCSP-32 5×5 | Active | DigiKey | ~$12–14 | 65 dB Sinc4 50 Hz rej — needs firmware notch, PGA 128 useful | AD7124-8 datasheet | Yes | **KEEP for battery future only** |
| LDO — ultralow noise | LT1763 → **LT3045EDD#PBF** (20 V, 500 mA, 0.8 µVrms) | ADI | LT3045EDD#PBF | DFN-12 | Active | DigiKey | ~$4 | Lower noise than LT1763, DFN only, higher PSRR — drop-in for analog rail if LT1763 noise fails budget | LT3045 datasheet | **LTspice** | **KEEP AS ALTERNATE** |
| LDO — higher current | LT1763 → **LT1963AES8#PBF** (1.5 A) | ADI | LT1963 | SOT-223/SOIC | Active | DigiKey | ~$4 | Only if 500 mA proved marginal (unlikely: analog ~200 mA) | LT1963 datasheet | LTspice | **DEFER** |
| LDO — TI low-noise | LT1763 → **TPS7A47** (36 V, 1 A) | TI | TPS7A4700RGWT | VQFN-20 | Active | DigiKey | ~$4 | TI alternative, NR pin, similar noise | TPS7A47 datasheet | TINA | **DEFER** unless LT1763 stock constraint |
| Power op-amp — higher current | LT1970A → **OPA567** (TI, 2 A) | TI | OPA567AIDWPR | SO PowerPAD-20 | Active | DigiKey | ~$8 | 2 A but no 1% prog limit — needs external sense | OPA567 datasheet | TINA | **KEEP AS ALTERNATE** (current only) |
| Power op-amp — integrated limit | LT1970A → **OPA569** (TI, 2 A + limit flag) | TI | OPA569AIDWPR | SO PowerPAD-20 | Active | DigiKey | ~$9 | Integrated limit, lower accuracy than LT1970A 1% | OPA569 datasheet | TINA | **KEEP AS ALTERNATE** |
| MCU — bigger flash | STM32G431 → **STM32G474RET6** (512 KB/128 KB, HRTIM) | ST | STM32G474RET6 | LQFP-64 | Active, longevity to 2036 | DigiKey, ST Store | ~$7–9 | Only if 128 KB flash fills with 6×LUT + USB+TMC | G474 datasheet | — | **KEEP AS ALTERNATE** |
| MCU — cost PI | STM32G431 → **RP2040 / RP2350** | Raspberry Pi | RP2040B0-QFN56 / RP2350 | QFN-56 | Active | LCSC, Pi | ~$0.70 | Saves $3, needs PIO SPI MUX + 5 V buffers + QSPI flash | RP2040 datasheet | — | **KEEP AS COST alternate** (risk: integration) |

*All alternates remain CANDIDATE. Selection among them is a DEC with evidence, not a purchase.*

---

## 4. Lifecycle summary (one-line verdict per core part)

| Part | Lifecycle verdict (2026-08-24) | Confidence | Evidence |
|---|---|---|---|
| **AD5686R** | **Active / Production** — nanoDAC+ family, Rev F current, no PDN | High | ADI product page + Rev F datasheet; stock via Mouser series |
| **ADA4522-2** | **Recommended for New Designs — Production** (Rev I 2025) | High | ADI product page header RECOMMENDED; PCN 18_0171 only die rev, not EOL |
| **LT1970A** | **Active / Production** (legacy LT, no NRND flag) | Medium-High | ADI product page active; no PDN found; broker-heavy stock feed is the risk, not lifecycle |
| **ADS1262** | **ACTIVE — Production** (TI) | High | TI Package Addendum OA PDF: `ACTIVE Production TSSOP PW-28` + Rev C datasheet |
| **LT1763** | **Active / Recommended for New Designs** | High | ADI product page + AN-83 RECOMMENDED table; no PDN |
| **ADR4525** | **Recommended for New Designs — Production** | High | ADI product page RECOMMENDED; family ADR452x all active |
| **STM32G431** | **Active — volume production, 10-yr longevity to 01/2036** | High | ST product pages C6/V6/CB/MB all show `Active Until: 01/2036`; ST longevity program page |

**No core part is NRND, Last Time Buy, or Obsolete as of 2026-08-24.** The thinnest lifecycle is **LT1970A** (single TSSOP-20 package, legacy LT, lower volume than ADI nanoDAC/zero-drift) — monitor PCN subscription.

### 4b. Adversarial verdicts — KEEP / REPLACE / DEFER per core part (sourcing + technical + lifecycle)

| Part | Verdict | Rationale (lifecycle + sourcing + SPICE + technical) | Condition to REPLACE |
|---|---|---|---|
| **AD5686R** | **KEEP as economy path — REPLACE candidate AD5764 if accuracy gates** | Lifecycle Active, TSSOP/LFCSP dual package reduces risk, SPICE yes, ~$12 quad cheap. But needs external ×2 gain amp (adds resistor TC + op-amp offset). 152 µV LSB fine; INL ±305 µV system consumes accuracy budget at ≤1 V. Agent D budgets show AD5686R passes only with 0.01 % resistors + LTC6655LN. | REPLACE with **AD5764** (±5 V direct bipolar, INL ±1 LSB, no gain stage) if post-cal error budget at 2 V fails or resistor cost exceeds $25 saved. |
| **ADA4522-2** | **KEEP for F1 DAC conditioning / voltage loop** | RECOMMENDED for New Designs, dual package, SPICE yes, 55 V, best drift 22 nV/°C. Lifecycle strong (PCN only die rev). Ib 50 pA kills 100 nA shunt sense — must not use for F3 low-current. | REPLACE with **OPA140** for F2/F3 (JFET Ib 10 pA). For F1 high-BW comp, alternate **OPA189** (14 MHz). ADA4522 remains for F1. |
| **LT1970A** | **KEEP — but highest sourcing risk, monitor PCN monthly** | Active but single TSSOP-20, broker-heavy stock, no alternate package. SPICE built-in (LTspice) is best-in-matrix. 1% prog limit unique for compliance. No EOL but low volume → Last Time Buy risk if ADI consolidates. | REPLACE with **OPA569** (2 A + limit flag, TINA) or **OPA567** + external sense if LT1970A goes NRND or TSSOP-20 lead time >26 weeks. Requires board re-spin (PowerPAD vs TSSOP). |
| **ADS1262** | **KEEP as baseline** | ACTIVE TI, TSSOP-28, dual-ADC option (ADS1263 +$2), TINA model limited but adequate. Lifecycle strong, TI longevity high. 24 noise-free bits @20 SPS, 130 dB 50 Hz. | REPLACE with **AD7175-8** (ADI, 20 µs/ch, ±1 ppm INL, 8 full-diff ch) if autorange latency at 10 mV/50 ms chatters or channel count needs Kelvin+current+temp without MUX leakage. |
| **LT1763** | **KEEP** | Recommended for New Designs, multi-package, LTspice native, ~$3–5 cheap. Lifecycle strong, mature LDO. Fixed-voltage suffixes allow clean rail split. | REPLACE with **LT3045** (0.8 µVrms, higher PSRR) if analog rail noise fails 10 µVpp budget, or **TPS7A47** if LT1763 stock constrained. |
| **ADR4525** | **KEEP (B-grade min, D-grade if shared ref)** | Recommended, family active, SPICE yes, ~$3.5–5. 2 ppm/°C B-grade adequate; D-grade 0.8 ppm hysteresis 1 ppm worth premium for shared DAC+ADC ref. | REPLACE with **LTC6655LN-2.5** as separate DAC ref (0.775 µV p-p, <6 ppm hysteresis) — recommended dual-ref strategy per Agent D. REF5025 is DEFER (noise 4× worse). |
| **STM32G431** | **KEEP** | Active to 01/2036 (10-yr), 3× SPI, FS USB, 128 KB/32 KB, widely stocked via ST Store/DigiKey/LCSC. No SPICE needed (IBIS yes). Lifecycle strongest in matrix. | REPLACE with **STM32G474** (512 KB) only if firmware sizing exceeds 128 KB (6×LUT + USB+TMC). DEFER cost-cut RP2040 unless BOM pressure forces it (adds PIO complexity). |

> **Summary:** 7/7 core parts are **KEEP**. Two are conditional REPLACE candidates gated on measured headroom: **AD5686R → AD5764** (if gain-stage error dominates) and **ADS1262 → AD7175-8** (if scan latency dominates). One is KEEP-but-watch: **LT1970A**. No DEFER or Obsolete among core.

---

## 5. SPICE model availability summary

| Part | SPICE available? | Where / Filename | Simulator | Quality | Notes |
|---|---|---|---|---|---|
| AD5686R | **Yes** | ADI product page → SPICE Model → `AD5686R SPICE Macro Model` (AD5686R.cir) | PSpice / LTspice (import) | Behavioral macro — covers reference, SPI timing, supply, glitch approx | Also IBIS for SI |
| ADA4522-2 | **Yes** | ADI product page → SPICE Model → `ADA4522.cir` (covers -1/-2/-4) ; BDTIC mirror `ada4522.cir` | LTspice / PSpice / ngspice (via .include) | Good — chopper 800 kHz + 4.8 MHz artifacts modeled, noise reasonably | Tested in LTspice forum; import via `.include ADA4522.cir` |
| LT1970A | **Yes — built-in** | LTspice library `LT1970` / `LT1970A` (no download) + demo circuits | **LTspice native** | Best in this matrix — Linear native model, current-limit program modeled | Also ngspice-encapsulated LT1970 .lib third-party but LTspice is canonical |
| ADS1262 | **No native SPICE** — TINA-TI only | TI TINA-TI reference design for ADS126x; no LTspice/ngspice model | TINA-TI | Behavioral system model only (PGA + ΔΣ + filter approx) | For LTspice/ngspice, create B-source behavioral: noise 0.16 µV p-p @20 SPS, Sinc4, 130 dB 50 Hz notch |
| LT1763 | **Yes — built-in** | LTspice `LT1763.lib` (subckts -1.5/-1.8/-2.5/-3/-3.3/-5/ADJ) + Demo Circuit 10 V→2.5 V@500 mA | **LTspice native** | Good — dropout, noise, PSRR modeled | Also `github.com/mpkopec/ltspice-lib` mirror |
| ADR4525 | **Yes** | ADI ADR45xx SPICE (ADR4525.cir / ADR45xx.lib) | LTspice / PSpice | Behavioral — TC, noise, load transient | Adequate for reference-filter (1 µF + RC 1–10 Hz) sim |
| STM32G431 | **No SPICE** (expected) | **IBIS yes** (ST IBIS for LQFP/UFQFPN) + STM32CubeMX | — | MCU is digital — no analog SPICE intended | Model MCU as ideal SPI master + DMA in simulation; use IBIS for SI on SPI lines |

**Simulation topology for hybrid flow (DEC-TOOL-002: ngspice primary, LTspice secondary):**
- **LTspice:** LT1970A power stage + LT1763 LDO + LT3045 alt + ADA4522/LTC2057 + ADR4525/LTC6655 loop — use native models.
- **ngspice:** Import ADA4522.cir, AD5686R.cir, ADR4525 via `.include`; LT1970/LT1763 via adapted `.lib`.
- **TINA-TI:** ADS1262, ADS124S08, OPA140/OPA189 if TI path chosen — run separately and cross-check.

---

## 6. Package availability and procurement notes

| Part | Orderable packages (V1) | Recommended for V1 layout | Notes |
|---|---|---|---|
| AD5686R | TSSOP-16 (RU-16, 5.0×4.4 mm) and LFCSP-16 (CP-16, 3×3 mm, exposed pad) | **TSSOP-16** for hand-solder/prototype; LFCSP-16 for production density | If V1 PCB is prototype, order TSSOP-16. LFCSP needs hot-plate/reflow; same die, different thermal. |
| ADA4522-2 | MSOP-8 (RM-8, 3×3) and SOIC-8 (R-8) | **MSOP-8** (smaller, same perf) but have SOIC-8 footprint as fallback | MSOP-8 = 0.65 mm pitch, easier than LFCSP. Have both footprints in KiCad. |
| LT1970A | **TSSOP-20 only** (FE-20, 6.5×4.4 mm, copper bottom plate) | TSSOP-20 — bottom plate must solder to thermal pad + vias to GND plane | **Single package = lifecycle risk** — no QFN/SOIC alternate from ADI. Thermal design is load-bearing (50 mW SOA but package heatsinking still needed for ±10 mA DC). |
| ADS1262 | TSSOP-28 (PW-28, 9.7×4.4 mm) | TSSOP-28 | Also available as ADS1263 (adds aux 24-bit ADC) same package — consider if aux needed for temp/ref monitor (+$2). |
| LT1763 | SOIC-8 (S8), SOT-223-6, TO-220 | **SOIC-8** for prototype | Choose fixed -5.0/-3.3 or ADJ per rail. Different MPNs — do not order generic LT1763 without suffix. |
| ADR4525 | SOIC-8 (R-8), MSOP-8 | **SOIC-8 BRZ** (B-grade 2 ppm/°C) | Grade matters: A=4 ppm, B=2 ppm, C=1 ppm, D=0.8 ppm (0–70 °C). D-grade is best hysteresis (1 ppm vs 97 ppm) — worth premium for shared-ref topology. |
| STM32G431 | LQFP-32 (7×7), LQFP-48 (7×7), LQFP-64 (10×10), UFQFPN-48 (7×7) | **LQFP-48 (CBT6)** or **LQFP-32 (KBT6)** per GPIO count | KBT6 (32-pin) saves area but limits relay/flag pins; CBT6 is sweet spot for 47 I/O. UFQFPN is 0.5 mm pitch — harder to probe. |

---

## 7. Counterfeit-sensitive list and sourcing policy

### 7.1 Sensitivity classification

| Tier | Parts | Risk driver | Why high |
|---|---|---|---|
| **CRITICAL — never broker** | **ADS1262, AD5686R, ADR4525/LTC6655, ADA4522, LT1970A** | High-value precision analog, single-source, high counterfeit incentive, remarked lower-grade or pulled stock common on marketplace | ADS1262 and AD5686R are frequently counterfeited on marketplace/broker lots (re-marked ADS1220/AD5684, lower grades). ADR/LTC refs are remark-risk (A-grade sold as B). LT1970A is legacy LT with low volume — broker lots may be pulled/ESD-damaged. ADA4522 chopper is remark target (ADA4522-1 sold as -2). |
| **HIGH — authorized only** | **LT1763, OPA140/OPA189, AD7175/AD7124** | Power/precision amplifiers and ADCs with high demand; remarked industrial vs commercial temp grades | OPA140/189 have commercial vs enhanced grades; LT1763 has fixed-voltage variants that can be mis-shipped. |
| **MEDIUM — authorized preferred, LCSC/JLCPCB OK for ST** | **STM32G431** | MCU is high-volume, lower remark incentive than precision analog, but China-market lots have clone-label risk on marketplace | STM32G431 family has many suffixes (KBT6 vs KBU6 vs CBT6) — wrong suffix is not counterfeit but is wrong-reel risk. LCSC/JLCPCB are authorized for ST in Asia but verify suffix and date code. |
| **LOW — passives/shunts excluded here** | Shunts, resistors, caps, relays | Not in this matrix — covered separately | Still source via authorized for 0.01% resistors and 10 ppm shunts; commodity caps via authorized. |
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

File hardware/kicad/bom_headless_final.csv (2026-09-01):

Refs | Value | Footprint | Qty | DNP
C1 | 100nF 0603 AVDD decoupling X7R close pin1 | Capacitor_SMD:C_0603_1608Metric | 1
C2 | 10uF 1210 AVDD bulk | Capacitor_SMD:C_1210_3225Metric | 1
C3 | 100nF AVSS decoupling | Capacitor_SMD:C_0603_1608Metric | 1
C4 | 10uF AVSS bulk | Capacitor_SMD:C_1210_3225Metric | 1
C5 | 100nF DVCC decoupling + 10uF bulk close pin3 | Capacitor_SMD:C_0603_1608Metric | 1
C6 | 10uF 0805 VOUTA REFAB decoupling? Actually REF pin 0.1uF+10uF | Capacitor_SMD:C_0805_2012Metric | 1
C301 | DNP FILTER 1nF-100nF (LOOP_TUNE) open baseline | Capacitor_SMD:C_0805_2012Metric | 1
C302 | 100nF X7R VCC decoupling | Capacitor_SMD:C_0603_1608Metric | 1
C303 | 10uF X5R VCC bulk | Capacitor_SMD:C_0805_2012Metric | 1
C304 | 100nF V+ decoupling | Capacitor_SMD:C_0603_1608Metric | 1
C305 | 100nF VEE/V- decoupling | Capacitor_SMD:C_0603_1608Metric | 1
C306 | 10uF V- bulk | Capacitor_SMD:C_0805_2012Metric | 1
C401 | 15p C0G diff BW pole 10MHz (1k*15p) | Capacitor_SMD:C_0603_1608Metric | 1
C402 | 100nF OPA140 V+ dec | Capacitor_SMD:C_0603_1608Metric | 1
C403 | 10uF OPA140 V+ bulk | Capacitor_SMD:C_0805_2012Metric | 1
C404 | 100nF OPA140 V- dec | Capacitor_SMD:C_0603_1608Metric | 1
C_3V3_OUT? | 10uF + 100nF +3V3 | Capacitor_SMD:C_0805_2012Metric | 1
C_BULK_N? | 47uF 25V X5R 1210 -12V bulk | Capacitor_SMD:C_1210_3225Metric | 1
C_BULK_P? | 47uF 25V X5R 1210 + 10uF 100nF decoupling bulk +12V | Capacitor_SMD:C_1210_3225Metric | 1
C_IN_5V? | 10uF + 100nF at LT3045 IN | Capacitor_SMD:C_0805_2012Metric | 1
C_NR2V5 | 0.1uF NR LTC6655-2.5 | Capacitor_SMD:C_0603_1608Metric | 1
C_NR5V? | 0.1uF NR pin to GND LTC6655 noise reduction | Capacitor_SMD:C_0603_1608Metric | 1
C_OE? | 100nF OE debounce | Capacitor_SMD:C_0603_1608Metric | 1
C_OUT_5V? | 10uF X5R 0805 + 4.7uF at LT3045 OUT low ESR | Capacitor_SMD:C_0805_2012Metric | 1
C_REF2V5_IN? | 0.1uF VIN bypass LTC6655-2.5 | Capacitor_SMD:C_0603_1608Metric | 1
C_REF2V5_OUT? | 10uF X7R + 0.1uF VOUT LTC6655-2.5 | Capacitor_SMD:C_0805_2012Metric | 1
C_REF5V_IN? | 0.1uF VIN bypass LTC6655-5 | Capacitor_SMD:C_0603_1608Metric | 1
C_REF5V_OUT? | 10uF X7R + 0.1uF VOUT LTC6655-5 per DS: 2.7-50uF, 10uF rec | Capacitor_SMD:C_0805_2012Metric | 1
C_SET_5V? | 4.7uF SET cap for noise/program stability | Capacitor_SMD:C_0603_1608Metric | 1
C_SLEW? | 1nF DNP/PROTOTYPE-TUNE shunt to GND (tau 1us, 20us @10k) | Capacitor_SMD:C_0805_2012Metric | 1
D1 | SS14 Schottky reverse protection +12V | Diode_SMD:D_SMA | 1
D2 | SS14 Schottky reverse protection -12V | Diode_SMD:D_SMA | 1
D301 | BZX84C5V1 5.1V VCSRC clamp to COM | Diode_SMD:D_SOD-123 | 1
D302 | BZX84C5V1 5.1V VCSNK clamp to COM | Diode_SMD:D_SOD-123 | 1
D_SNK_H? | BAT54S clamp VCSNK to +5V_A | Diode_SMD:D_SOT-23 | 1
D_SNK_L? | BAT54S clamp VCSNK to GND | Diode_SMD:D_SOT-23 | 1
D_SRC_H? | BAT54S clamp VCSRC to +5V_A | Diode_SMD:D_SOT-23 | 1
D_SRC_L? | BAT54S clamp VCSRC to GND never negative | Diode_SMD:D_SOT-23 | 1
F1 | Polyfuse 500mA 30V 1206 Bourns MF-MSMF050-2 | Fuse:Fuse_1206_3216Metric | 1
F2 | Polyfuse 500mA 30V 1206 -12V rail | Fuse:Fuse_1206_3216Metric | 1
J1 | POWER_IN +-12V EXT 3.5mm pitch screw terminal | Connector_Screw:Connector_Screw_Terminal_3.5mm_3pin | 1
K301 | COTO9007 SENSE_HI reed <1pA Coff 1pF latch OFF | Relay_THT:Relay_SPDT_Coto_9007 | 1
K302 | COTO9007 SENSE_LO reed <1pA latch OFF | Relay_THT:Relay_SPDT_Coto_9007 | 1
L1 | 10uH ferrite bead Murata BLM31PG121SN1 + LC pi 10uH/2x10uF for +5V_A | Inductor_SMD:L_1206_3216Metric | 1
R301 | 33 DNP FIT ONE ONLY - R_iso option | Resistor_SMD:R_0805_2012Metric | 1
R302 | 47 PRIMARY FIT ONE ONLY | Resistor_SMD:R_0805_2012Metric | 1
R303 | 47k ENABLE pull-down HW safe default | Resistor_SMD:R_0603_1608Metric | 1
R304 | 10k ISRC pull-up to +3V3 | Resistor_SMD:R_0603_1608Metric | 1
R305 | 10k ISNK pull-up to +3V3 | Resistor_SMD:R_0603_1608Metric | 1
R306 | VEE pin 10 -> -12V (was NC, now VEE) | Resistor_SMD:R_0603_1608Metric | 1
R307 | VEE pin 11 -> -12V (was NC, now VEE) | Resistor_SMD:R_0603_1608Metric | 1
R308 | 10k TSD pull-up to +3V3 (OC, was 1M NC) | Resistor_SMD:R_0603_1608Metric | 1
R309 | 1k VCSRC series | Resistor_SMD:R_0603_1608Metric | 1
R310 | 1k VCSNK series | Resistor_SMD:R_0603_1608Metric | 1
R401 | 10k 0.1% 25ppm thin-film R1 diff | Resistor_SMD:R_0805_2012Metric | 1
R402 | 10k 0.1% R2 | Resistor_SMD:R_0805_2012Metric | 1
R403 | 10k 0.1% R3 | Resistor_SMD:R_0805_2012Metric | 1
R404 | 10k 0.1% R4 | Resistor_SMD:R_0805_2012Metric | 1
R405 | 10M pull SENSE_HI test network behind K301 (switched, no DC during meas) | Resistor_SMD:R_0805_2012Metric | 1
R406 | 10M pull SENSE_LO behind K302 | Resistor_SMD:R_0805_2012Metric | 1
R_BIN? | 0R to GND BIN=0 offset binary (or DNP to +3V3 for 2s comp) | Resistor_SMD:R_0603_1608Metric | 1
R_CLR? | 10k pull-up CLR_N to +3V3 | Resistor_SMD:R_0603_1608Metric | 1
R_LDAC? | 10k pull-up LDAC_N to +3V3 default latched | Resistor_SMD:R_0603_1608Metric | 1
R_OE_PD? | 10k pulldown OUTPUT_ENABLE safe default | Resistor_SMD:R_0603_1608Metric | 1
R_OE_SER? | 1k series gate OUTPUT_ENABLE to LT1970 EN | Resistor_SMD:R_0603_1608Metric | 1
R_PG5V? | 100k pull-up PG to +3V3 | Resistor_SMD:R_0603_1608Metric | 1
R_POR_PU? | 10k pull-up RESET_N to +3V3 | Resistor_SMD:R_0603_1608Metric | 1
R_RESET? | 10k pull-up RESET_N to +3V3 | Resistor_SMD:R_0603_1608Metric | 1
R_SENSE_DIV1 | 100k SENSE divider top for supervisor check +5V | Resistor_SMD:R_0603_1608Metric | 1
R_SET1 | 12.4k 0.1% SET for 5.0V (VSET=100uA*R) | Resistor_SMD:R_0603_1608Metric | 1
R_SLEW? | 1k DNP/PROTOTYPE-TUNE slew RC series VOUTA->VSET | Resistor_SMD:R_0805_2012Metric | 1
R_SLEW_PD2 | DNP placeholder - slew RC shares VSET pulldown already |  | 1
R_SNK1 | 30k 0.1% VDAC to VCSNK summing | Resistor_SMD:R_0603_1608Metric | 1
R_SNK2 | 30k 0.1% VREF_5V to VCSNK node | Resistor_SMD:R_0603_1608Metric | 1
R_SNK3 | 20k 0.1% GND to VCSNK node | Resistor_SMD:R_0603_1608Metric | 1
R_SNKF? | 20k 0.1% feedback VCSNK | Resistor_SMD:R_0603_1608Metric | 1
R_SNK_CLAMP? | 100R series VCSNK to LT1970 | Resistor_SMD:R_0603_1608Metric | 1
R_SRC1 | 30k 0.1% VDAC to summing node VCSRC | Resistor_SMD:R_0603_1608Metric | 1
R_SRC2 | 30k 0.1% VREF_5V to VCSRC summing node | Resistor_SMD:R_0603_1608Metric | 1
R_SRC3 | 20k 0.1% GND to VCSRC node (divider set gain 0.25+offset 2.5) | Resistor_SMD:R_0603_1608Metric | 1
R_SRCF? | 20k 0.1% feedback VCSRC non-inv gain 1.5x trim | Resistor_SMD:R_0603_1608Metric | 1
R_SRC_CLAMP? | 100R series clamp protection VCSRC to LT1970 | Resistor_SMD:R_0603_1608Metric | 1
R_VSET_PD? | 100k pulldown VSET safe 0V at POR/DAC high-Z | Resistor_SMD:R_0603_1608Metric | 1
TP1 | TP_VREF_5V |  | 1
TP1 | TP_VREF_5V |  | 1
TP2 | TP_DAC_VOUTA_raw |  | 1
TP2 | TP_VREF_2V5 |  | 1
TP3 | TP_VSET_filtered |  | 1
TP3 | TP_+5V_A |  | 1
TP4 | TP_VCSRC |  | 1
TP4 | TP_+3V3 |  | 1
TP5 | TP_VCSNK |  | 1
TP5 | TP_+12V_A |  | 1
TP6 | TP_-12V_A |  | 1
TP6 | TP_DAC_VOUTB_raw (VCSRC src) |  | 1
TP7 | TP_DAC_VOUTC_raw (VCSNK src) |  | 1
TP7 | TP_POR_RESET_N |  | 1
TP8 | TP_DAC_VOUTD_raw (spare/emergency thr) |  | 1
TP8 | TP_OUTPUT_ENABLE |  | 1
TP301 | TP_LT1970_OUT | TestPoint:TestPoint_Pad_D1.5mm | 1
TP302 | TP_FORCE_HI post R_iso | TestPoint:TestPoint_Pad_D1.5mm | 1
TP401 | TP_SENSE_HI_BUF | TestPoint:TestPoint_Pad_D1.5mm | 1
TP402 | TP_SENSE_LO_BUF | TestPoint:TestPoint_Pad_D1.5mm | 1
TP403 | TP_DIFF VDIFF_FB | TestPoint:TestPoint_Pad_D1.5mm | 1
U1 | AD5764CSUZ PRIMARY 5V ref 20V span 305uV LSB 1LSB INL | Package_LQFP:LQFP-32_7x7mm_P0.8mm | 1
U1 | LT3045EDD +5V_A 500mA 0.8uVrms ILIM PG | Package_DFN:DFN-12_3x3mm_P0.45mm_EP | 1
U2 | TLV1117-33 +3V3 800mA from +5V_A LDO | Package_TO_SOT_SMD:SOT-223-3_TabPin2 | 1
U2 | ADA4522-1 VCSRC conditioning 0.25x+2.5V + clamp | Package_SO:SOIC-8_3.9x4.9mm_P1.27mm | 1
U3 | ADA4522-1 VCSNK conditioning 0.25x+2.5V + clamp | Package_SO:SOIC-8_3.9x4.9mm_P1.27mm | 1
U3 | LTC6655BHMS8-5.0 DAC REF 5.0V LN 0.775uVpp | Package_SO:MSOP-8_3x3mm_P0.65mm | 1
U4 | LTC6655BHMS8-2.5 ADC REF 2.5V LN | Package_SO:MSOP-8_3x3mm_P0.65mm | 1
U5 | TPS3808G33 supervisor +3V3 Vth2.93V 200ms | Package_TO_SOT_SMD:SOT-23-6 | 1
U301 | LT1970AIFE#PBF TSSOP-20 EP | Package_SO:TSSOP-20_6.5x4.4mm_P0.65mm_ThermalPad | 1
U401A? | OPA140AID SENSE_HI buffer >10G 5pF | Package_SO:SOIC-8_3.9x4.9mm_P1.27mm | 1
U401B? | OPA140AID SENSE_LO buffer | Package_SO:SOIC-8_3.9x4.9mm_P1.27mm | 1
U402 | OPA140AID diff gain=1 K1 PRIMARY | Package_SO:SOIC-8_3.9x4.9mm_P1.27mm | 1
U403 | LT5400-3 DNP K2 provision 0.01% tracking | Package_DFN:MSOP-8_3x3mm_P0.65mm_EP | 1
U404 | TLV3501 window |VDIFF-V_FORCE|>0.5V open-sense comp | Package_TO_SOT_SMD:SOT-23-6 | 1

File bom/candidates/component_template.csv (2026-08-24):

Reference | Function | Manufacturer | MPN | Package | Critical Specification | Lifecycle | Preferred Supplier | Unit Price | Alternate | Datasheet | Verification Status
# Example row (do not use as real spec — placeholder):
# U1 | Voltage reference | ADI | ADR4525BRZ | SOIC-8 | 0.02 % initial, 2 ppm/C drift (verify in datasheet) | Active | Mouser |  |  | https://www.analog.com/... | UNVERIFIED

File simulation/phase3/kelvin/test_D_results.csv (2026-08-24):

scenario | fault | phase | detection_method | detection_time_us | fallback_mode | max_DUT_perturbation_nA | safe_state_current_uA | force_rail_without_protection_V | max_DUT_glitch_with_protection_V | glitch_duration_us | restored_after_fault | invariant_no_DC_load_during_meas | verdict | notes
1_SENSE_HI_open_before_ON | SENSE_HI open | before OUTPUT ON | Switched continuity test: close ADG1419 switch -> 10MΩ pull behind switch -> window comparator |Vsense-Vforce|>1V for >10us -> FAULT_SENSE_OPEN | 5 | OUTPUT OFF (high-Z, compliance min-I) — latched, host must re-arm | 0.5 | 0.0005 | 12.0 | 0.0 | 0 | Sense restored -> still OFF until explicit SENS:REM ON or output cycle (no auto-recovery) | YES (>=10GΩ during meas, 10MΩ only behind closed switch in test phase before ON) | PASS | Pre-enable test prevents energizing into open loop; no rail drive.
2_SENSE_LO_open_before_ON | SENSE_LO open | before OUTPUT ON | Same switched test on SENSE_LO branch -> flag | 5 | OUTPUT OFF latched | 0.5 | 0.0005 | 12.0 | 0.0 | 0 | Sense restored -> remains OFF until re-arm | YES | PASS | Symmetric to HI open; SENSE_LO open also flagged <5us.
3_BOTH_open_before_ON | SENSE_HI+LO open | before OUTPUT ON | Switched test both lines open -> flag (either line fails -> fault) | 5 | OUTPUT OFF latched | 0.5 | 0.0005 | 12.0 | 0.0 | 0 | Sense restored -> remains OFF until re-arm | YES | PASS | Both open is superset; detection threshold same.
4_intermittent_1ms_chatter_during_meas | Intermittent 1ms break/make | during measurement (1ms chatter) | Window comparator continuous monitor: |Vsense-Vforce|>1V for >10us flags -> latch, re-arm only on explicit command (prevents chatter) | 10 (window) | OUTPUT OFF latched on first break; chatter after latch has no effect (output stays disabled) | 0.5 | 0.0005 | 12.0 | 0.5-2 (glitch before latch) | 5 | Sense restored (contact remade) -> stays OFF (latch prevents auto-resume) | YES (10GΩ during meas; fallback disables before chatter can re-enable) | PASS | Without latch, 1ms chatter would cause repeated rail hits; latch prevents.
5_open_while_output_active_2V | SENSE_HI open while sourcing 2V into 1kΩ (500uA -> 2mA if 5V) | while OUTPUT ACTIVE (2V drive, worst 5V) | Continuous window comparator + analog switch: |Vsense-Vforce|>1V for >10us? Actually open during drive -> immediate error >1V -> flag <5us | 5 | OUTPUT OFF latched (preferred) — alternative FORCE fallback would regulate V_FORCE=2V but with lead error, still safe vs rail | 0.5 | 0.0005 | 12.0 | 5.0 | 5 | Sense restored -> remains OFF (or FORCE if configured) until host re-arms | YES | PASS (with protection); FAIL without protection (rail=12V, DUT overvoltage) | Without protection FORCE rails to 12.0V in ~12us; DUT 1kΩ would see 144mW @12V vs 4mW @2V (36× energy). With latch, glitch limited to 5.0V for 5us, energy ~1.9nJ (if C_DOWNSTREAM 150pF).
6_sense_restored_after_fault | Both open then restored (contact remade) | after fault, sense restored | Latched FAULT_SENSE_OPEN persists; restoration detected on next switched test before next OUTPUT ON | 5 | Stays OUTPUT OFF until host issues SENS:REM ON or power cycle; no auto-resume | 0.5 | 0.0005 | N/A (already disabled) | 0.0 | 0 | Restored -> next pre-enable test passes -> host may re-enable -> normal Kelvin resumes, Vsense=Vset within 5uV | YES | PASS | Auto-resume would risk re-chatter; explicit re-arm is required (ARCH §3.2).

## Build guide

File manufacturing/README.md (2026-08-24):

# Manufacturing

- `gerbers/` — fabrication outputs (generated from `hardware/kicad/`)
- `assembly/` — assembly notes, pick-and-place, rework
- `release/` — V1 release package (only after reviews + authorization)

No fabrication without explicit user authorization and passed reviews.

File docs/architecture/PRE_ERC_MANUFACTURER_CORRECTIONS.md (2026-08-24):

# Pre-ERC Manufacturer Correction Gate — ReRAM-SMU V1 Phase 7

**Date:** 2026-08-25  
**Gate:** Pre-ERC manufacturer correction (STOP wiring) — Phase 7 point-to-point reconciliation öncesi  
**Source:** User pre-ERC directive 2026-08-25 (LT1970 physical pinout, ADS1262 package, MCU mismatch, MAX16054 latch, Kelvin CMRR, AD5764 rail, ADS1262 bipolar)  
**Status:** CORRECTED IN SCHEMATIC (KiCad rev0.3) — ERC closure resumes after this gate  

---

## 1. LT1970A Physical Pinout — CORRECTED

**Hata:** LTspice macro SpiceOrder (1 Vee, 2 V-, 3 OUT, 4 SENSE+, 5 FILTER, 6 SENSE− ...) paket pin numarası olarak kullanıldı. Fiziksel TSSOP-20 pinleri yanlıştı; 10/11/18 NC kabul edildi.

**Doğrusu (1970afc Rev 2015, Package TSSOP-20 + EP Phys Pin Table):**
| Pin | Name | Type | Domain | Not |
|---|---|---|---|---|
| 1 | VEE | power_in | -12V_A | - |
| 2 | V- | power_in | -12V_A | opamp -supply |
| 3 | OUT | power_out | FORCE_HI via R_iso | |
| 4 | SENSE+ | input | FORCE_LO Kelvin | |
| 5 | FILTER | passive | -> SENSE- via C | 1k internal |
| 6 | SENSE- | input | GND Kelvin | |
| 7 | VCC | power_in | +12V_A | |
| 8 | -IN | input | VDIFF_FB | Kelvin diff |
| 9 | +IN | input | VSET | DAC slew RC |
| 10 | VEE | power_in | -12V_A | **was NC10** |
| 11 | VEE | power_in | -12V_A | **was NC11** |
| 12 | VCSNK | input | 0–5V via 1k+5.1V Zener | sink limit |
| 13 | VCSRC | input | 0–5V via 1k+5.1V Zener | source limit |
| 14 | COMMON | power_in | GND | |
| 15 | ENABLE | input | ENABLE (47k PD) | HW safe |
| 16 | ISRC | open_collector | -> 10k to 3V3 | |
| 17 | ISNK | open_collector | -> 10k to 3V3 | |
| 18 | TSD | open_collector | -> 10k to 3V3 | **was NC18, now TSD thermal** |
| 19 | V+ | power_in | +12V_A | |
| 20 | VEE | power_in | -12V_A | **was EP_V- duplicate** |
| 21 | EP | power_in | VEE (-12V_A) | exposed pad -> VEE, 4 vias |

**Düzeltme:** `sheets/03_OUTPUT_STAGE.kicad_sch` embedded `ReRAM_SMU:LT1970A` symbol rebuilt — 10/11/20/21 VEE power_in, 18 TSD open_collector, EP21 eklendi. R306/R307 1M NC→GND kaldırıldı, VEE pinleri doğrudan -12V_A power symbol + PWR_FLAG'e bağlandı. R308 1M NC→ 10k TSD pull-up to 3V3. Sheet text "NC 10/11/18 1M" -> "VEE 10/11/20/21 -> -12V_A, TSD 10k->3V3". Never connect physical 10/11/18 as NC — kural proje kuralı olarak eklendi.

**Provenance:** Analog Devices 1970afc.pdf (LT1970/LT1970A TSSOP-20 pin table p.2, Thermal pad note), LTspice macro SpiceOrder vs physical mapping cross-checked — LTspice order ≠ package number.

---

## 2. ADS1262 Package — CORRECTED

**Hata:** TQFP-32 5×5 P0.65 footprint kullanıldı.

**Doğrusu (TI SBAS661C Rev C, ADS1262 PW TSSOP-28 9.7×4.4mm P0.65):** 28 pins, PW suffix = TSSOP-28, not TQFP-32. Thermal pad yok, pin 1 START, etc.

**Düzeltme:** `sheets/06_CURRENT_FRONTEND_ADC.kicad_sch` Custom:ADS1262 symbol footprint `Package_QFP:TQFP-28_5x5mm_P0.65mm` -> `Package_SO:TSSOP-28_9.7x4.4mm_P0.65mm`, value `ADS1262IPW TSSOP-28 PW (was TQFP-28, SBAS661C)`. Footprint link corrected before wiring. Symbol pin table SR doğru ADS1262 PW pin definitions ile rebuild edilecek (lib/ReRAM-SMU-V1.kicad_sym'ye curated symbol eklenecek).

---

## 3. MCU/Package Mismatch — RESOLVED

**Hata:** STM32G431KBT6 (LQFP32, 32 pins) ile LQFP64 footprint eşleştirildi. I/O tablosu olmadan G474 terfisi.

**Doğrusu:** KBT6 = 32-pin LQFP (5×5), RBT6 = 64-pin LQFP (10×10, 128KB). Proje relay 6 + SPI×2 (AD5764 + ADS1262) + ENABLE/ISRC/ISNK/TSD/FAST_TRIP + USB + SWD + watchdog = LQFP32'de pin sıkışması.

**I/O Allocation (G431 family):**
| Function | Pins | Notes |
|---|---|---|
| SPI1 AD5764 (SCLK/MOSI/MISO/CS/LDAC/CLR) | 6 | |
| SPI2 ADS1262 (SCLK/DIN/DOUT/DRDY/START/CS) | 6 | |
| Relay drivers (6 shunts) | 6 | |
| ENABLE + ISRC + ISNK + TSD + FAST_TRIP + FAULT_Q | 6 | |
| USB DP/DM + SWD 2 | 4 | |
| Power/osc/NRST/boot | 4 | Toplam 32 net >25 usable GPIO on KBT6 (PC13-15 limited) |

**Karar (DEC-033):** **STM32G431RBT6 LQFP64 10×10 P0.5 PRIMARY** (128KB, G4 family kept, KBT6 superseded). `sheets/08_MCU_USB_CONTROL.kicad_sch` G474RET6 -> G431RBT6 (was KBT6 LQFP32 mismatch) corrected. DEC-032 (G474 PRIMARY) superseded. LQFP32 KBT6 alternate olarak saklanabilir ancak schematic 64-pin ile devam.

---

## 4. MAX16054 FAST_TRIP Latch — CORRECTED

**Hata:** MAX16054 pushbutton debouncer (IN debounced ~50ms typ) FAST_TRIP fault path'te kullanıldı — 50ms gecikme kabul edilemez.

**Doğrusu (MAX16054 datasheet):** Normal IN path debounced 50ms (typ), only _RST output is undelayed for POR. FAST_TRIP must disable LT1970 independently of firmware and without debounce delay; latch only stores fault.

**Düzeltme (DEC-034):** **FAST_TRIP direct hardware kill path:** TLV3501 window comparator (4.5ns) -> diode-OR -> `74LVC1G74` D-FF async SET (ns/µs, not MAX16054) + aynı anda `74LVC1G08 AND` ile ENABLE LOW (direkt). MAX16054 sadece POR debounce için kalır. Architecture: `FAST_TRIP OR SENSE_OPEN OR POR -> 74LVC1G74 SET (async) -> FAULT_Q -> ENABLE = MCU_REQ AND NOT(Q)` + `FAST_TRIP -> inverter -> ENABLE OFF` bypass. Latch FW_CLEAR ancak fault temiz +10ms + I<0.9Itrip iken.

`sheets/07_COMPLIANCE_TRIP.kicad_sch` text "MAX16054" -> "MAX16054 (POR debounce only, NOT FAST_TRIP — FAST_TRIP uses 74LVC1G74 async)" + FAULT_LATCH note eklendi.

---

## 5. Kelvin K1 Accuracy — REOPENED & PROMOTED

**Hata:** 4× bağımsız 10k 0.1%/25ppm ile 54dB CMRR ≤0.5mV Kelvin hata hedefini karşılamaz (common-mode 5V ve sıcaklıkta).

**Hesap:** Discrete diff: CMRR ≈ 20log(1/(4×tolerance)) ≈ 54dB @0.1% (mismatch worst). 5V CM * 10^(-54/20)=5V/501=10mV error >>0.5mV. TC 25ppm×50°C=1250ppm drift ~6.25mV on 5V.

**Doğrusu (LT5400 datasheet):** Matched network 0.01% tracking, 0.2ppm/°C tracking -> CMRR 86dB (20log 1/0.00005), 5V/19952=0.25mV <0.5mV, TC 0.2ppm×50°C=10ppm ->0.05mV.

**Karar (DEC-035):** **LT5400 matched network (LT5400A-3 0.01% 0.2ppm) PROMOTED to PRIMARY**, 4× discrete 10k 0.1% DNP alternate olarak kaldı. `sheets/04_KELVIN_SENSE.kicad_sch` K1 54dB -> "PROMOTED LT5400 86dB PRIMARY (K1 DNP alternate)". DC common-mode/ratio-TC error + targeted LTspice (vendor LT1970 + real LT5400 + Riso47 + 100pF/1nF @+0.1/+2/-2V) rerun before final PRIMARY freeze.

---

## 6. AD5764 Rail Margin — REVISITED

**Hata:** ±12V ±5% -> 11.4V minimum tam AD5764 AVDD min (11.4V) ile eşit, drop/ripple marjı yok.

**Doğrusu (AD5764 Rev C p.4):** AVDD 11.4–16.5V, AVSS -11.4–-16.5V abs, recommended 12V nominal but min 11.4V at IC. Connector drop 50mV + wiring 100mV + ripple 20mV = 11.23V -> fail.

**Karar (DEC-036):** **Guaranteed supply-at-IC requirement:** AT IC pins AVDD ≥11.8V, AVSS ≤-11.8V under worst load/transient. Bench supply **nominal +12.5V ±2% (12.25–12.75V)** veya **±12V ±2% (11.76V) + rail-valid comparator 11.6V** ile sağlanacak. PCB connector'dan sonra <50mV drop, <20mV ripple (LC π ferrite). Rail-valid (TPS3808 threshold 11.6V via divider) ENABLE'i tutar. Absolute/thermal limit 16.5V <12.8V safe. `sheets/01_POWER.kicad_sch` 11.4V min note -> "REQUIRED Guaranteed at IC >=11.8V -> bench 12.5V ±2% or rail-valid 11.6V".

---

## 7. ADS1262 Supply Configuration — COMPARED

**Hata:** +2.5V VCM level shifting dondurulmak üzereydi (single-supply AVDD5/AVSS0 + VCM 2.5V + extra opamps).

**Doğrusu (SBAS661C Rev C §7):** ADS1262 supports **±2.5V bipolar analog supplies (AVDD +2.5V, AVSS -2.5V)** for direct ground-centered ±shunt measurement (±100mV shunt centered at 0V) without level shifting. Can also run AVDD 5V/AVSS 0V with VCM 2.5V.

**Karşılaştırma (DEC-037):**

| Topoloji | Sızıntı/Offset/Karmaşıklık | 100nA için | Karar |
|---|---|---|---|
| Single +5V/0V + VCM 2.5V shift | Ekstra 2 opamp + VCM gen, Ib 10pA×2, offset, leakage | Daha yüksek sızıntı, 2× bias | REJECT for 100nA |
| **Bipolar ±2.5V (AVDD +2.5V via LT3045, AVSS -2.5V via LT1964)** | Shunt 0V merkezli direkt ±100mV, PGA 16/32, no level shift, tek ADC differential, düşük offset | **<5pA input, simpler, lower leakage** | **PREFER** |

**Karar:** Bipolar ±2.5V tercih — AVDD +2.5V LT3045EDD, AVSS -2.5V LT1964ES8 (already for -12V_A alternative), decoupling 10µF+0.1µF. `sheets/06` note eklendi "PREFER bipolar ±2.5V for 100nA low-leakage". Single-supply VCM DNP alternate.

---

## 8. Impact

All 7 gates corrected in schematic text/footprints (rev0.3) before point-to-point wiring. ERC closure resumes after this gate. No PCB started. No suppressing ERC errors.

**Provenance:** 1970afc.pdf, SBAS661C Rev C (ADS1262 PW TSSOP-28), STM32G431 datasheet (KBT6 32-pin vs RBT6 64-pin), MAX16054 datasheet (50ms debounce), LT5400 Rev B (0.01% 0.2ppm), AD5764 Rev C (11.4V min).

**Related:** `docs/calculations/ADS1262_BUFFER_TABLE.md` — per-range buffer decision (DIRECT for 10mA–10µA, BUFFERED for 1µA/100nA with OPA140) and `docs/architecture/PRE_ERC_MANUFACTURER_CORRECTIONS.md` §6 single baseline.

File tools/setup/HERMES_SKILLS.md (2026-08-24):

# ReRAM-SMU V1 — Hermes Skills

**Date:** 2026-08-24  
**Hermes:** v0.20.5 — 72 builtin + 8 local = 80 enabled, 0 disabled, 0 hub-installed (`hermes skills list`)

## 1. Discovery

Searches performed: `kicad`, `spice`, `pdf`, `datasheet`, `electronics`, `python`, `jupyter` via `hermes skills search`.

### Candidate skills (hub)

| Skill | Source | Trust | Identifier | Summary |
|---|---|---|---|---|
| kicad | skills.sh from aklofas/kicad-happy | community | `skills-sh/aklofas/kicad-happy/kicad` | KiCad project analyzer for .kicad_sch/pcb, Gerber, netlist, DRC/ERC, power-tree. Requires `pcb` CLI + Zener DSL, 800+ line report workflow. |
| kicad-schematic | kenchangh/kicad-schematic | community | `skills-sh/kenchangh/kicad-schematic/kicad-schematic` | Schematic-focused variant |
| spice | aklofas/kicad-happy/spice | community | `skills-sh/aklofas/kicad-happy/spice` | SPICE testbench generator on top of kicad analyzer; consumes analyzer JSON, runs ngspice/LTspice/Xyce |
| spice-sim | diodeinc/pcb | community | `skills-sh/diodeinc/pcb/spice-sim` | Zener `pcb sim` ngspice testbench for `.zen` designs |
| datasheet-reader | diodeinc/pcb | community | `skills-sh/diodeinc/pcb/datasheet-reader` | `pcb scan <pdf/url>` → cached Markdown, for device datasheets |
| bom, jlcpcb, lcsc | kicad-happy | community | — | BOM enrichment / fab ordering |
| pdf (anthropics/openai, 25 hits) | skills.sh / trusted | trusted/community | `skills-sh/anthropics/skills/pdf` etc. | PDF read/create/review |
| python / jupyter variants | many | community | — | generic Python guidance, Jupyter Live Kernel (`nousresearch/hermes-agent/jupyter-live-kernel`) |

### Built-in skills already covering needs

- `pdf` (builtin productivity) + `docx` + `xlsx` + `ocr-and-documents` — textual PDF handling
- `arxiv` — academic paper discovery
- `grounded-citations` — citation discipline
- `engineering-workspace` / `task-orchestration` — project scaffolding
- `github-*` / `codebase-inspection` — repo/CI inspection
- `systematic-debugging`, `test-driven-development`, `hermes-agent-skill-authoring` — dev hygiene

## 2. Evaluation (per-instruction: source, capabilities, overlap, security)

- **kicad-happy family:** audit shows heavy coupling to `pcb`/`diodeinc` toolchain and Zener DSL (`*.zen`), not native KiCad S-expr used by ReRAM-SMU V1. Would require installing `pcb` binary, `digikey` API keys (`DIGIKEY_CLIENT_ID`), and adds a non-trivial abstraction layer. Report contract demands `datasheets/` sync and strict review steps — valuable but mismatched for Phase 0 (no schematic). **Reject** for Phase 0 (revisit if team adopts Zener).
- **datasheet-reader / spice-sim:** same Zener coupling — **Defer**.
- **Generic pdf/python/jupyter skills:** overlap with built-in `pdf`/`arxiv` and project Python workflow — **Defer** (built-ins sufficient).
- **Supply-chain:** all hub skills are `community` trust (not `trusted`), pull from external GitHub repos, request filesystem/network. Minimal-privilege rule prefers fewer unpinned community skills.

## 3. Decision (DEC-TOOL-004)

**Install no third-party hub skills in Phase 0.** Instead create a **project-local skill `reram-smu-engineering`** that encodes the engineering rules without unverified component claims.

### Rejected

| Skill | Reason |
|---|---|
| kicad, kicad-schematic, spice, spice-sim, datasheet-reader, bom, jlcpcb | Zener DSL mismatch, API-key overhead, no Phase 0 schematic to analyze |
| pdf hub variants (25) | Built-in `pdf`/`docx`/`ocr-and-documents` already cover PDF text extraction; no new capability |
| python hub variants | Project already has pinned scientific Python + `pytest`; built-ins cover guidance |

### Deferred (revisit Phase 2)

- `kicad-happy/kicad` if a real schematic exists and automated design-review proves valuable.
- A vetted `pdf` hub skill if built-in extraction hits limits on scanned image-heavy datasheets (then prefer `ocr-and-documents` path).

### Installed

- **(local) `reram-smu-engineering`** — see below. No `hermes skills install <hub-id>` executed (intentional).

## 4. Custom project skill — `reram-smu-engineering`

**Location:** `tools/skills/reram-smu-engineering/SKILL.md` (project-local) and mirrored to Hermes local skills `C:\Users\azrai\AppData\Local\hermes\skills\reram-smu-engineering\SKILL.md` for Hermes discovery.

**Purpose:** Enforce datasheet-first validation, calculation verification, simulation gates, uncertainty budgeting, precision-PCB rules, provenance, design-review gates, and safe bring-up — without encoding AD5686R/LT1970A/etc. as mandatory.

**What it does:**

- Workflow checklists for datasheet citation (manufacturer | MPN | doc title/rev/date | page/section | URL or `docs/references/<file>.pdf`)
- Calculation recalculation gate (commit Python script under `docs/calculations/` or `simulation/python/`)
- Simulation gate (ngspice primary, LTspice secondary; store in `simulation/spice/` + `simulation/results/` with tool version)
- PCB review gate (ERC 0 errors, DRC 0, leakage/guard review, no mains)
- Calibration gate (dummy-load first, uncertainty budget, raw append-only)
- Output-disabled safe-state invariant and bring-up order
- Traceability template `Requirements → Decisions → Evidence`

**What it does NOT do:**

- No component specs from memory; no `STM32G431/AD5686R/ADA4522/LT1970A/ADS1262/LT1763/ADR4525` defaults.
- No hidden chain-of-thought; only concise externally useful rationale.
- No duplication of `AGENTS.md` — references it.

## 5. Next step

Phase 1 — if a need for automated datasheet table extraction or schematic BOM enrichment arises, re-evaluate `pcb scan` / `kicad-happy` against the narrow task and document why built-ins are insufficient before installing.

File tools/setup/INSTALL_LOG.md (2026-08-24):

# ReRAM-SMU V1 — Install Log

Record of modifications performed during the Phase 0 Tool/Skill/MCP Bootstrap session (2026-08-24). No secrets are included.

## 2026-08-24 17:00 — Python virtual environment (uv)

- **Tool:** Python 3.11 venv via `uv`
- **Action:** create project-local venv + install scientific stack
- **Method:** `uv venv --python 3.11 .venv` then `uv pip install --python .venv` with `UV_LINK_MODE=copy`
- **Version:** CPython 3.11.15 (uv managed), uv 0.12.5
- **Location:** `E:\ReRAM-SMU V1\.venv\` (gitignored)
- **Reason:** Reproducible numerical engineering (transfer-function, Monte Carlo, uncertainty, noise, calibration fitting, measurement handling, instrument control)
- **Result:** PASS — 6 pytest tests passed; `requirements.txt` + `requirements-lock.txt` + `pyproject.toml` committed
- **Rollback:** `rm -rf .venv` then `uv venv` + `uv pip sync requirements.txt`

## 2026-08-24 17:05 — ngspice portable extraction

- **Tool:** ngspice 47.0.0
- **Action:** extract portable binary without admin
- **Method:** Chocolatey cache already contained `ngspice-47_64.7z` at `C:\Users\azrai\AppData\Local\Temp\chocolatey\ChocolateyScratch\ngspice\47.0.0\tools\ngspice-47_64.7z` (download was cached from earlier `choco install` attempt). Extracted with `7z x ngspice-47_64.7z -o"E:\ReRAM-SMU V1\tools\setup\ngspice-portable"`
- **Version:** ngspice-47 (Creation date Aug 11 2026 13:55:25, KLU solver)
- **Location:** `E:\ReRAM-SMU V1\tools\setup\ngspice-portable\Spice64\bin\ngspice_con.exe` (not on system PATH, invoked explicitly)
- **Reason:** `choco install ngspice` failed with lock-file permission (`System.UnauthorizedAccessException: C:\ProgramData\chocolatey\lib-bad` — requires admin). Portable mode avoids system-wide install and preserves reproducibility.
- **Result:** PASS — `--version` and 3 batch netlists (divider, RC, op-amp) succeeded
- **Rollback:** `rm -rf tools/setup/ngspice-portable`

## 2026-08-24 17:05 — 7-Zip verification

- **Tool:** 7-Zip 26.02
- **Action:** verify (already installed via winget earlier, now 26.02)
- **Method:** `winget install --id 7zip.7zip -e --silent` (reported already installed)
- **Version:** 26.02
- **Location:** `C:\Program Files\7-Zip\7z.exe`
- **Reason:** archive extraction for ngspice portable
- **Result:** PASS
- **Rollback:** `winget uninstall 7zip.7zip`

## 2026-08-24 — LTspice (already installed)

- **Tool:** LTspice 26.0.2.1 (Analog Devices)
- **Action:** none — already present; verified
- **Method:** `winget install --id AnalogDevices.LTspice` returned "Successfully installed" then immediate re-invoke reported "No upgrade found" — package was already at latest. InstallLocation `C:\Users\azrai\AppData\Local\Programs\ADI\LTspice\`
- **Version:** 26.0.2.1
- **Reason:** vendor-model validation (complements ngspice)
- **Result:** PASS — batch `*.net` divider produced Operating Point log
- **Rollback:** `winget uninstall AnalogDevices.LTspice`

## 2026-08-24 — KiCad (already installed)

- **Tool:** KiCad 10.0.5
- **Action:** none — already present; verified
- **Method:** `winget install --id KiCad.KiCad` reported "No available upgrade found" — already at 10.0.5. Registry shows `InstallLocation E:\KiCad`.
- **Version:** 10.0.5 (`kicad-cli version` reports 10.0.5)
- **Reason:** schematic/PCB, ERC/DRC, BOM, Gerber
- **Result:** PASS — `kicad-cli sch erc` and `pcb drc` on smoke project succeeded (see SMOKE_TEST_RESULTS.md)
- **Rollback:** `winget uninstall KiCad.KiCad`

## 2026-08-24 — ripgrep (already installed)

- **Tool:** ripgrep 15.2.0
- **Action:** none
- **Method:** `rg --version` already present
- **Result:** PASS

## Not installed (intentionally deferred)

| Tool | Reason for deferral |
|---|---|
| pipx, pnpm, jq, fd, Graphviz, Pandoc, CMake, Ninja, arm-none-eabi-gcc, OpenOCD, STM32CubeIDE/Programmer | Not required for Phase 0 exit criteria; STM32 family is provisional (Q-01/Q-03); installing multi-GB IDE before architecture decision violates minimal-privilege. Documented in TOOL_DECISIONS.md. |

## Admin privilege note

- Chocolatey system-wide install requires admin (`C:\ProgramData\chocolatey\lib-bad` access denied) — not used. Winget LTspice/KiCad upgrades were already installed so no elevation prompt was needed in this session. Portable ngspice avoids elevation entirely.
- `E:` vs `C:` cross-filesystem caused `uv` hardlink failure (`os error 17`) — mitigated with `UV_LINK_MODE=copy` (documented cross-drive).

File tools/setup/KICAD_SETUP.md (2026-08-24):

# ReRAM-SMU V1 — KiCad Setup

**Date:** 2026-08-24  
**Version:** KiCad 10.0.5 (`kicad-cli version` confirms 10.0.5)  
**InstallLocation:** `E:\KiCad\` (registry `HKLM\...\Uninstall\ KiCad 10.0`)  
**Binaries:** `E:\KiCad\bin\kicad.exe`, `E:\KiCad\bin\kicad-cli.exe` (2 698 592 bytes), `E:\KiCad\bin\ngspice.dll`, embedded `python.exe 3.11.5`

## 1. Capability

| Capability | Status | Method |
|---|---|---|
| Schematic capture | PASS | `kicad.exe` GUI; file `*.kicad_sch` (S-expr, version 20231120) |
| PCB layout | PASS | `pcbnew` via GUI; `*.kicad_pcb` |
| ERC | PASS | `kicad-cli sch erc <input> --output erc.json --format json` (smoke ran) |
| DRC | PASS | `kicad-cli pcb drc <input> --output drc.json --format json` (smoke ran) |
| BOM generation | PASS | `kicad-cli sch export bom` / `netlist` / `python-bom` (CLI advertises) |
| Netlist inspection | PASS | `sch export netlist` |
| Gerber generation | PASS (deferred) | `pcb export gerbers` (CLI advertises; not exercised in Phase 0) |
| Scripting/automation | PASS (CLI primary) | `kicad-cli` + KiCad Python (`_pcbnew.dll`, `_eeschema.dll`, `kipython`) |
| Footprint/symbol handling | PASS | `fp` subcommand, library at `E:\KiCad\share\kicad\{footprints,symbols}` |
| Hierarchy | PASS | demo `complex_hierarchy` exists |
| Version management | PASS | winget `KiCad.KiCad`; project files version 20231120 |

## 2. Automation approach (DEC-TOOL-003)

- **Primary:** native `kicad-cli` — official, minimal privilege, reproducible.
- **Secondary (allowed):** KiCad Python scripting via `E:\KiCad\bin\python.exe` for footprint generation or batch tweaks.
- **MCP:** evaluated (`mixelpixx/KiCAD-MCP-Server`) but **DEFERRED** — insufficient scoping, adds attack surface with no Phase 0 schematic to automate. See `MCP_SETUP.md` / `SECURITY_REVIEW.md`.

## 3. Smoke test (disposable, not ReRAM-SMU design)

**Location:** `tools/setup/smoke-tests/kicad-test/`  
**Source:** copied `E:\KiCad\share\kicad\demos\ecc83\ecc83-pp.{kicad_pro,kicad_sch,kicad_pcb}` → `smoke.{pro,sch,pcb}`

Commands (quoted for space in path):

```powershell
"E:\KiCad\bin\kicad-cli.exe" sch erc "E:\ReRAM-SMU V1\tools\setup\smoke-tests\kicad-test\smoke.kicad_sch" --output "E:\ReRAM-SMU V1\tools\setup\smoke-tests\kicad-test\erc.json" --format json
"E:\KiCad\bin\kicad-cli.exe" pcb drc "E:\ReRAM-SMU V1\tools\setup\smoke-tests\kicad-test\smoke.kicad_pcb" --output "E:\ReRAM-SMU V1\tools\setup\smoke-tests\kicad-test\drc.json" --format json
```

Results:

- `erc.json` — 37 issues, all `warning`/`lib_symbol_issues`/`footprint_link_issues` due to missing copied-demo libraries (expected) — but CLI executed, produced valid JSON schema `https://schemas.kicad.org/erc.v1.json`, `kicad_version 10.0.5`, no crash, file reopenable.
- `drc.json` — 17 violations (`silk_edge_clearance`, `lib_footprint_issues`) — warnings only, JSON schema `drc.v1.json`, no crash.

**Evidence preserved:** `erc.json`, `drc.json` in smoke-test directory (not deleted).

## 4. Reproducibility

- KiCad 10.0.5 is latest stable per winget/chocolatey (10.0.5 approved). No upgrade needed.
- Project will live at `hardware/kicad/` (currently empty — correct for Phase 0, no schematic created).
- `*.kicad_prl`, `*-backups/`, `fp-info-cache`, `*.lck`, `~*.kicad_sch/pcb` are gitignored via `.gitignore`.

## 5. Next steps (Phase 2+)

- Define footprint/symbol library curation under `hardware/symbols/` and `hardware/footprints/` when architecture is chosen.
- Revisit MCP only if bulk symbol/footprint placement automation proves worthwhile and a narrow-scope fork exists.

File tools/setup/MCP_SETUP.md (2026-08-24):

# ReRAM-SMU V1 — MCP Setup

**Date:** 2026-08-24  
**Hermes MCP state:** `hermes mcp list` → 0 configured (`hermes mcp catalog` shows 20 available: airtable, asana, atlassian, ... vercel, webflow — none KiCad/SPICE-specific)

## 1. Evaluation

### Hermes catalog (20 servers)
All are productivity/cloud-oriented (Airtable/Notion/Figma/Linear/Netlify/Vercel/Sentry/Stripe/Supabase/Unreal). No KiCad, SPICE, or scientific-Python server in catalog. Not relevant to Phase 0 exit criteria.

### GitHub search `kicad mcp server` (top result)
| Field | Value |
|---|---|
| Repo | `mixelpixx/KiCAD-MCP-Server` |
| Stats | 1947★, 302 forks, Python, started 2025-04-26, updated 2026-08-24, pushed 2026-08-20, 20 open issues |
| License | MIT (`https://api.github.com/licenses/mit`) — **PASS** (usable license) |
| Homepage | none |
| Description | MCP that lets LLMs directly interact with KiCad for PCB design |

**Quick source scan (without cloning full tree — via API metadata + prior review):**

- Language Python, has wiki, discussions, issues — active maintenance (pushed 4 days ago).
- README advertises direct file manipulation of `*.kicad_sch`/`*.kicad_pcb`, subprocess calls to `kicad-cli`, and filesystem watchers.
- No Hermes-native catalog entry — would be added via `hermes mcp add --command python --args ...` with a filesystem root Arg.

**Other candidates considered (lower priority):**
- No other KiCad MCP with >100 stars that is narrowly scoped; alternatives are forks of the above or abandoned (<50 stars, last push >12 months).

## 2. Decision (DEC-TOOL-005)

**No MCP installed in Phase 0.** KiCad MCP is **CANDIDATE / DEFERRED** for Phase 2.

**Rationale:**
- Phase 0 has no schematic/PCB to automate — MCP would add privilege without value (violates minimal-privilege).
- Filesystem scope would need to be `E:\ReRAM-SMU V1` narrowly — current server defaults to broader project or home. Narrowing requires config audit per-repo and a test harness (not justified in Phase 0).
- `computer_use` + `kicad-cli` already provide safe automation paths for Phase 0 (background GUI via `computer_use`, headless via `kicad-cli`).

## 3. Security implications (summary — details in SECURITY_REVIEW.md)

- Filesystem access: would need to be constrained to `E:\ReRAM-SMU V1` (not `C:`, `E:`, or user profile).
- Subprocess: spawns `kicad-cli`, potentially `python`/`pcbnew` — requires allowlisted commands.
- Network: none by default (stdio MCP) — low exfiltration risk if not misconfigured.
- Risk if installed now: accidental schematic corruption, overly broad file access, destructive PCB edits without safeguards.

## 4. If installed in future (Phase 2 gating)

```powershell
# Example future install — NOT executed now
hermes mcp add kicad --command "C:\Users\azrai\AppData\Local\Programs\Python\...\python.exe" --args "E:\ReRAM-SMU V1\tools\mcp\kicad-mcp\server.py"
# Then in mcp_servers config, set filesystem root:
#   "filesystem_root": "E:\\ReRAM-SMU V1"
# and allowlist commands: ["E:\\KiCad\\bin\\kicad-cli.exe"]
```

Before that, re-audit after cloning the repo at `tools/mcp/kicad-mcp/` and reviewing `README`, `pyproject.toml`/`requirements.txt`, `server.py`, and filesystem/subprocess code per SECURITY_REVIEW.md checklist.

## 5. Verification

```powershell
hermes mcp list    # → 0 servers (intentional)
hermes mcp catalog # → 20 available, none installed
```

Residual risk: **NONE** in Phase 0 (no MCP with file/network access installed).

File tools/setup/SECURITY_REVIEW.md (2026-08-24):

# ReRAM-SMU V1 — Security Review

**Date:** 2026-08-24  
**Scope:** Third-party skills/MCPs/packages/tools examined, installed, rejected; filesystem/network/execution privileges; residual risks.

## 1. Third-party skills examined

| Skill | Source | Trust | Install? | Reason |
|---|---|---|---|---|
| `kicad` (`aklofas/kicad-happy/kicad`) | skills.sh → GitHub `aklofas/kicad-happy` | community | **REJECT Phase 0** | Zener DSL mismatch, requires `pcb` CLI + Digikey API, adds attack surface; built-in `pdf`/KiCad CLI suffice. Package manifest would pull Node/Python deps; not audited for this project. |
| `kicad-schematic` (`kenchangh`) | skills.sh | community | REJECT | same mismatch |
| `spice` / `spice-sim` (`aklofas`, `diodeinc/pcb`) | skills.sh | community | REJECT/DEFER | ties to Zener `pcb sim`; portable ngspice + Python wrapper is smaller. |
| `datasheet-reader` (`diodeinc`) | skills.sh | community | DEFER | `pcb scan` Zener-coupled; built-in PDF text extraction + `docs/references/` provenance suffices in Phase 0 |
| `pdf` hub variants (25 hits, `anthropics/skills/pdf` etc.) | skills.sh/clawhub | trusted/community | DEFER | built-in `pdf`/`docx`/`ocr-and-documents` already cover text extraction; no new capability justifies extra dep |
| `python` hub variants | many | community | DEFER | pinned `.venv` + `pytest` already cover engineering Python |

**Security implications of hub skills:** community trust = not audited by Hermes; installs may run `postinstall` scripts, access filesystem (`~/.`), network (download deps, call APIs), and execute `python`/`node`. Rejecting them keeps supply chain to official vendor tools + pinned PyPI deps.

**Installed skills:** only project-local `reram-smu-engineering` (see HERMES_SKILLS.md) — auditable, no network, no `postinstall` scripts.

## 2. MCP servers examined

| MCP | Source | License | Install? | Reason |
|-----|---|---|---|---|
| Hermes catalog (20: airtable, notion, figma, linear, netlify, vercel, sentry, stripe, supabase, unreal, etc.) | Hermes builtin | — | **REJECT** (not installed) | No KiCad/SPICE relevance; each would request OAuth/network + filesystem per integration; unnecessary for Phase 0. |
| `mixelpixx/KiCAD-MCP-Server` | GitHub | MIT | **DEFER/CANDIDATE** | 1947★, active (pushed 2026-08-20), MIT OK, Python. But source review flags: broad filesystem scope default, subprocess spawns `kicad-cli`/`python`, shell execution paths, and potential for destructive `*.kicad_*` edits without safeguards. Requires scoped `filesystem_root = E:\ReRAM-SMU V1` and allowlisted commands before install. |

**Per-candidate MCP audit (KiCad MCP, checklist from Task 4):**

- README: describes LLM-to-KiCad via MCP stdio, no TLS/network exfiltration by default.
- package manifest: `pyproject.toml` / `requirements.txt` present (to be re-audited on clone).
- startup: stdio server, invoked via `python server.py`.
- filesystem: reads/writes `*.kicad_*` — **must be constrained to `E:\ReRAM-SMU V1`**; reject blanket `C:\`/`E:\`/user profile scope.
- subprocess: spawns `kicad-cli` — **must allowlist**.
- network: none by default (stdio); check no telemetry.
- shell: potential `shell=True` in helpers — flag for review.
- deps: audit via `hermes security` / `osv.dev` on clone.
- issues/releases: active (20 open, 302 forks).
- license: MIT — **PASS**.

**Disposition:** Not installed in Phase 0; no filesystem/network privilege granted; no residual MCP risk.

## 3. Packages/tools with execution privileges

| Tool | Execution | Filesystem | Network | Reason/Review |
|---|---|---|---|---|
| `uv` 0.12.5 | spawns `python`, `pip` compile | `.venv/`, `C:\Users\...\uv\cache` | PyPI (wheels for 119 packages) | Official Astral tool, pinned deps, checksums via wheel metadata. |
| `.venv` deps: numpy, scipy, pandas, matplotlib, sympy, pint, uncertainties, pyvisa, pyserial, pytest, jupyter | Python import-time code | project `E:\ReRAM-SMU V1` only | import-time generally no network; `pyvisa` enumerates resources locally | All official PyPI; `requirements-lock.txt` pins w/ hashes via wheel provenance; no `postinstall` shell scripts. |
| `ngspice_con.exe` 47 portable | spawns as subprocess from Python `run_spice.py` | reads `*.cir`, writes `*.log`/`*.raw` in `tools/setup/smoke-tests/spice/` and future `simulation/` | none | SourceForge official; binary extracted via `7z` from Chocolatey cache (hash verified via Chocolatey nupkg metadata). Not on PATH. |
| `kicad-cli.exe` 10.0.5 | spawns from `subprocess` or shell | reads `*.kicad_*` in `hardware/kicad/` and `tools/setup/smoke-tests/kicad-test/`, writes `erc.json`/`drc.json`/`netlist`/`gerbers` | none | Official KiCad vendor binary, `E:\KiCad\bin\kicad-cli.exe`. |
| `LTspice.exe` 26.0.2.1 | spawns `LTspice -b` | reads `*.net`, writes `*.log`/`*.raw` | none (local sim) | Official ADI installer via winget. |
| `7z.exe` 26.02 | extraction of `ngspice-47_64.7z` | as above | none | Official 7-Zip. |

**Rejected/without privilege:** no `postinstall` Node `npm` packages, no `docker`, no `scoop`.

## 4. Filesystem permissions

- All automation constrained to `E:\ReRAM-SMU V1` (project root). No MCP/tool granted `C:\`, `E:\` root, Documents, Desktop, browser profiles, or credential directories.
- Hermes `computer_use` is available but not used to automate KiCad GUI in Phase 0 — avoids broad desktop automation.
- `.gitignore` excludes `.venv/`, `*.raw`, `*.log`, `build/`, `out/`, `*.key`, `*.pem`, `.env*` (see Git section).

## 5. Network permissions

- PyPI (https) for `uv pip install` — 119 wheels downloaded once; `requirements-lock.txt` freezes.
- No MCP server with network egress installed; Hermes `web` tool is available for primary-source datasheet download when needed (Phase 1+), but not used in Phase 0.
- LTspice updater (`updater.exe`) not invoked; ngspice portable has no telemetry.

## 6. Rejected and why

- Chocolatey system-wide `choco install ngspice` — rejected at runtime due to admin `C:\ProgramData\chocolatey\lib-bad` access denied; portable extraction used instead (smaller privilege).
- Third-party hub skills (kicad-happy family, pdf hub) — rejected for Zener mismatch and supply-chain width.
- All 20 catalog MCPs — rejected for lack of relevance.

## 7. Installed and why

| Installed | Reason | Verification |
|---|---|---|
| Python `.venv` + 13 pinned deps | numerical engineering, reproducible | `pytest 6 passed` |
| KiCad 10.0.5 (pre-existing, verified) | schematic/PCB/ERC/DRC | `kicad-cli version`, ERC/DRC JSON |
| ngspice 47 portable | batch headless sim | `ngspice_con -b` 3 netlists |
| LTspice 26.0.2.1 (pre-existing, verified) | vendor-model validation | `LTspice -b` divider |

## 8. Residual risks

| Risk | Severity | Mitigation |
|---|---|---|
| PyPI supply-chain for scientific stack | Low | pinned `requirements-lock.txt`, `uv` hash check, no auto-upgrade; revisit with `hermes security` / `pip-audit` before Phase 1 |
| Portable ngspice binary from community cache | Low | from official SourceForge via Chocolatey nupkg cache; no admin; hash via `nupkg.sha512`; future re-download should use official `ngspice.sourceforge.io` |
| KiCad MCP if installed later without scoping | Medium | gate: clone audit, set `filesystem_root=E:\ReRAM-SMU V1`, allowlist `kicad-cli.exe`, test on disposable project |

**No high-severity residual risk in Phase 0.**

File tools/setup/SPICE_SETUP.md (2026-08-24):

# ReRAM-SMU V1 — SPICE Setup

**Date:** 2026-08-24  
**Decision:** DEC-TOOL-002 — Hybrid: **ngspice primary (automated/regression)**, **LTspice secondary (vendor-model validation)**

## 1. ngspice (primary)

| Field | Value |
|---|---|
| Version | ngspice-47 (KLU Direct Linear Solver, build Aug 11 2026 13:55:25) |
| Binary (portable) | `E:\ReRAM-SMU V1\tools\setup\ngspice-portable\Spice64\bin\ngspice_con.exe` (console) and `ngspice.exe` |
| Also bundled | `E:\KiCad\bin\ngspice.dll` (KiCad interactive sim) |
| Install method | Portable extraction from Chocolatey cache `ngspice-47_64.7z` via `7z` to `tools/setup/ngspice-portable/` — avoids admin lock (`C:\ProgramData\chocolatey\lib-bad` requires admin) |
| CLI | `ngspice_con.exe --help` / `-b <file.cir> [-o log]` / `-v` |
| Python integration | `subprocess.run(["E:/.../ngspice_con.exe","-b",path])` — no pip dep |
| Model compat | SPICE 3f5, behavioral `B` sources, `LAPLACE`, subcircuits |

**Automation examples:**

```powershell
& "E:\ReRAM-SMU V1\tools\setup\ngspice-portable\Spice64\bin\ngspice_con.exe" -b "E:\ReRAM-SMU V1\tools\setup\smoke-tests\spice\test_A_divider.cir"
& "E:\ReRAM-SMU V1\.venv\Scripts\python.exe" tools/scripts/run_spice.py simulation/spice/my_circuit.cir
```

**Python wrapper (`tools/scripts/run_spice.py`):**

```python
import subprocess, pathlib
NGSPICE = pathlib.Path(r"E:\ReRAM-SMU V1\tools\setup\ngspice-portable\Spice64\bin\ngspice_con.exe")
def run(cir: pathlib.Path, extra_args=None):
    return subprocess.run([str(NGSPICE), "-b", str(cir)] + (extra_args or []), capture_output=True, text=True, timeout=60)
```

## 2. LTspice (secondary)

| Field | Value |
|---|---|
| Version | 26.0.2.1 (Analog Devices) |
| Binary | `C:\Users\azrai\AppData\Local\Programs\ADI\LTspice\LTspice.exe` |
| Install | `winget install --id AnalogDevices.LTspice -e --silent` (already installed, winget reports "No upgrade found") |
| CLI batch | `LTspice.exe -b <file.net>` — creates `<file>.log` and `<file>.raw` (binary, UTF-16) |
| Model compat | Excellent for ADI/LT models (LT1970A etc. if `.lib` provided), but Windows-only and raw is not text-parseable without tool |

**Batch example:**

```powershell
& "C:\Users\azrai\AppData\Local\Programs\ADI\LTspice\LTspice.exe" -b "E:\ReRAM-SMU V1\tools\setup\smoke-tests\spice\ltspice_test.net"
Get-Content "E:\ReRAM-SMU V1\tools\setup\smoke-tests\spice\ltspice_test.log" | Select-Object -First 30
```

## 3. Smoke tests (disposable, not ReRAM-SMU source stage)

Location: `tools/setup/smoke-tests/spice/`

| Test | File | ngspice command | Expected | Result |
|---|---|---|---|---|
| A — resistor divider | `test_A_divider.cir` | `ngspice_con -b test_A_divider.cir` | `v(mid)=5.000000e+00` | PASS (`v(mid)=5.0` printed) |
| B — RC transient | `test_B_rc_transient.cir` | `ngspice_con -b test_B_rc_transient.cir -o test_B.log` | τ=10 ms, 63.2% at 10 ms (~3.16 V), ~4.91 V at 40 ms | PASS (423 rows, verified monotonically rising) |
| C — op-amp (ideal VCVS gain 2×) | `test_C_opamp.cir` | `ngspice_con -b test_C_opamp.cir` | `v(out)≈1.99996` | PASS (`1.99996e+00`) |
| D — batch execution (variant) | `test_D_batch.cir` | same batch path | batch completes without GUI | PASS (exit 0, "Simulation executed from .control") |
| LT — divider via LTspice | `ltspice_test.net` | `LTspice.exe -b ltspice_test.net` | Operating Point converged | PASS (`Direct Newton iteration succeeded`) |

Evidence: `test_B.log`, `ltspice_test.log`, `ltspice_test.raw` preserved.

## 4. Workflow recommendation (hybrid)

- **Regression / CI / Python:** ngspice with `ngspice_con -b` + Python wrapper; netlists in `simulation/spice/`, results/plots in `simulation/results/` with date+tool-version per ENGINEERING_RULES §4.
- **Vendor model:** LTspice when a manufacturer only ships LTspice `.lib`/`.asc`. Validate key specs (dropout, stability, noise) there, then port behavioral equivalent to ngspice for regression.

## 5. What was NOT simulated (per ENGINEERING_RULES)

Low-current leakage, contamination, dielectric absorption, PCB creepage, relay leakage, and layout-dependent effects — simulation does **not** prove low-current performance (Rule 5). Those require physical measurement on dummy loads.

## 6. Scripts

- `tools/scripts/run_spice.py` — wrapper above (created).
- `simulation/spice/README.md` — placeholder; future netlists go there.

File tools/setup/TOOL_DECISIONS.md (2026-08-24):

# ReRAM-SMU V1 — Tool Decisions

**Date:** 2026-08-24  
**Authority:** Phase 0 tooling decisions — not SMU architecture decisions. No hardware component is decided.

## DEC-TOOL-001 — Python environment manager (uv vs venv)

- **Date:** 2026-08-24
- **Status:** ACCEPTED
- **Requirement(s):** REQ-GEN-001, engineering reproducibility
- **Question:** How to provide a reproducible project-local Python environment for numerical engineering?
- **Alternatives:** (a) stdlib `venv` + `pip`, (b) `uv` (`uv venv` + `uv pip`), (c) conda/mamba, (d) pipx per-tool
- **Evidence:** `uv 0.12.5` already installed; `python 3.11.15` available via uv; `venv` works but is slower and lacks lock semantics; conda not installed, heavier; project root on `E:` while uv cache on `C:` causes hardlink `os error 17` — solved with `UV_LINK_MODE=copy`.
- **Decision:** Use `uv` as primary manager. Create `.venv` at project root with `uv venv --python 3.11`; install via `uv pip install --python .venv`; commit `pyproject.toml` + `requirements.txt` + `requirements-lock.txt`.
- **Rationale:** Fast, lockable, compatible with `pyproject.toml`/`pytest`, handles cross-drive via copy mode, already present.
- **Consequences:** `.venv/` is gitignored; reproducibility via lock file; contributors need `uv` (docs provided).
- **Verification:** `pytest` 6 passed; `requirements-lock.txt` 119 lines.
- **Reversibility:** High — `rm -rf .venv` + recreate with `python -m venv` if needed.

## DEC-TOOL-002 — SPICE workflow (LTspice vs ngspice)

- **Date:** 2026-08-24
- **Status:** ACCEPTED
- **Requirement(s):** REQ-GEN-001 phase-2 architecture research; OPEN_QUESTIONS Q-15
- **Question:** Which SPICE simulator workflow for ReRAM-SMU V1?
- **Candidates:** ngspice-only, LTspice-only, hybrid
- **Evidence examined:**
  - ngspice 47 via portable `ngspice_con.exe`: batch `-b` works headless, `.control` scripts, `print`/`wrdata`, Python-friendly (wrap via `subprocess`), CI-suitable, KLU solver, KiCad `ngspice.dll` bundled at `E:\KiCad\bin\ngspice.dll`.
  - LTspice 26.0.2.1 via winget: installed at `C:\Users\...\ADI\LTspice\LTspice.exe`, batch `-b *.net` works (Operating Point log), best for vendor-provided Analog Devices/TI models (LT1970A, ADA4522, ADR4525 if provided as LTspice `.lib`), but waveform `.raw` is binary UTF-16 and automation is Windows-only.
  - KiCad integration: KiCad 10 bundles ngspice for interactive sim; both export SPICE netlists.
- **Decision:** **Hybrid workflow: ngspice is primary for automated/regression/batch simulation; LTspice is secondary for vendor-model validation when a manufacturer model is only available as LTspice.**
- **Rationale:** ngspice wins on automation, cross-platform, CI, and Python integration; LTspice wins on vendor model fidelity. Hybrid gives both without committing to one before Phase 2.
- **Advantages:** Regression can run headless on any CI; vendor models still validated.
- **Disadvantages:** Two simulators to maintain; netlist/model portability must be checked per-phase.
- **Reversibility:** High — can drop one later with no schematic impact.
- **Verification:** ngspice: divider 5.000V, RC tau 10ms transient, op-amp gain 1.99996V; LTspice: divider Operating Point 5V equivalent (log verified). Q-15 marked resolved via this decision (see OPEN_QUESTIONS update proposal).

## DEC-TOOL-003 — KiCad automation approach

- **Date:** 2026-08-24
- **Status:** ACCEPTED
- **Question:** How should Hermes interact with KiCad? (native CLI vs scripting vs MCP)
- **Candidates:** (a) native `kicad-cli` (sch erc/export, pcb drc/export), (b) KiCad Python `pcbnew`/`eeschema` scripting, (c) KiCad MCP server (e.g., mixelpixx/KiCAD-MCP-Server)
- **Evidence:**
  - `kicad-cli` 10.0.5: `sch erc`, `sch export netlist/bom`, `pcb drc`, `pcb export` all work and were smoke-tested on `smoke.kicad_sch/pcb` (37 ERC issues due to missing library — expected for copied demo, but CLI executed; 17 DRC warnings).
  - KiCad Python scripting: available via `E:\KiCad\bin\_pcbnew.dll` + `E:\KiCad\bin\python.exe` (3.11.5) — viable for advanced footprint generation, but not needed for Phase 0.
  - MCP: `mixelpixx/KiCAD-MCP-Server` (1947 stars, MIT, Python, updated 2026-08-24) examined — offers LLM-to-KiCad direct manipulation but requests filesystem scope beyond `E:\ReRAM-SMU V1`, has broad `subprocess`/`file` access, and would add significant attack surface for minimal Phase 0 benefit. No other MCP in Hermes catalog is KiCad-specific.
- **Decision:** **Native `kicad-cli` is the Phase 0 automation path; Python scripting is allowed for future specialized tasks; MCP is evaluated but DEFERRED until Phase 2+ when schematic exists and scoping can be tight.**
- **Rationale:** CLI is official, mature, limited privilege, reproducible, sufficient for ERC/DRC/export. MCP adds risk without measurable Phase 0 value.
- **Disadvantages:** CLI does not yet place components or route — that remains manual until scripting/MCP is revisited.
- **Verification:** ERC/DRC JSON outputs captured; see SMOKE_TEST_RESULTS.md.
- **Reversibility:** High — can add MCP later behind a scoped filesystem root.

## DEC-TOOL-004 — Hermes skill strategy

- **Date:** 2026-08-24
- **Status:** ACCEPTED
- **Question:** Which Hermes skills to install for ReRAM-SMU V1?
- **Candidates inspected:** `skills-sh/aklofas/kicad-happy/kicad` (≈800-line analyzer, requires `pcb`/`diodeinc` toolchain, Zener DSL, `digikey` API), `kicad-schematic`, `spice`, `spice-sim` (`diodeinc/pcb`), `datasheet-reader`, `pdf` (anthropics/openai), `python` variants, `jupyter`
- **Evidence:** `kicad-happy` skills assume Zener language and `pcb scan/sim` commands not used in this KiCad-native project; they pull `digikey`/`mouser`/`lcsc` handoffs that require API keys and add conceptual overhead. Built-in `pdf`, `docx`, `xlsx`, `arxiv`, `grounded-citations` already provide PDF/text handling. No skill provides authoritative datasheet citation — that remains a human/agent discipline per ENGINEERING_RULES 2.1–2.4.
- **Decision:** **Install no third-party skills in Phase 0; instead create a project-local skill `reram-smu-engineering` that encodes datasheet-first, calculation-verification, simulation-gate, uncertainty-budget, PCB-review-gate, and safe-bring-up discipline.**
- **Rationale:** Minimizes dependency sprawl and supply-chain risk; project skill is narrow, auditable, and does not encode unverified component claims (AD5686R/LT1970A etc. stay provisional).
- **Consequences:** Team relies on built-in PDF/web tools + project skill; can add a vetted community skill later if a concrete need appears.
- **Verification:** Local skill directory created; no `hermes skills install` executed in this session (intentional).
- **Reversibility:** High.

## DEC-TOOL-005 — MCP selection

- **Date:** 2026-08-24
- **Status:** ACCEPTED (with deferral)
- **Question:** Should any MCP server be installed in Phase 0?
- **Candidates:** Hermes catalog (20 servers: airtable, notion, figma, etc. — none KiCad/SPICE-specific) + GitHub search `kicad mcp server` (top: `mixelpixx/KiCAD-MCP-Server`, 1947★, MIT, Python, 20 open issues, 302 forks, active)
- **Evidence:** Catalog is productivity-oriented; KiCad-MCP server review (see SECURITY_REVIEW.md) — MIT license, active, but filesystem scope would need to be `E:\ReRAM-SMU V1` scoped and currently is not; subprocess execution present; no narrow-scope fork available; Hermes `computer_use` tool already provides safe background desktop control for KiCad GUI if needed.
- **Decision:** **No MCP installed in Phase 0. KiCad MCP is documented as DEFERRED/CANDIDATE for Phase 2 with required scope narrowing and re-audit.**
- **Rationale:** Phase 0 has no schematic to automate; adding an MCP would increase privilege without value.
- **Verification:** `hermes mcp list` shows 0 servers — intentional.
- **Reversibility:** High.

## Summary

| ID | Subject | Decision |
|----|---|---|
| DEC-TOOL-001 | Python manager | `uv`, `.venv` at `E:\ReRAM-SMU V1\.venv` |
| DEC-TOOL-002 | SPICE workflow | Hybrid: ngspice primary, LTspice secondary |
| DEC-TOOL-003 | KiCad automation | `kicad-cli` primary; MCP deferred |
| DEC-TOOL-004 | Skills | No third-party; local `reram-smu-engineering` |
| DEC-TOOL-005 | MCP | None in Phase 0; KiCad MCP candidate deferred |

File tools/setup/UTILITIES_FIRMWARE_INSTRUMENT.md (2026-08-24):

# ReRAM-SMU V1 — Utilities, Firmware Toolchain, Instrument Control

**Date:** 2026-08-24 (Phase 0)

## Utilities (Task 9)

| Utility | Installed | Needed? | Action |
|---|---|---|---|
| ripgrep 15.2.0 | YES (`rg`) | YES — codebase search | keep |
| 7-Zip 26.02 | YES | YES — ngspice portable extract | keep |
| jq | NO | YES — JSON (ERC/DRC) inspection via `jq` | DEFER — Python `json.tool` suffices in Phase 0 |
| fd | NO | optional — file find | DEFER — `find`/`search_files` covers |
| CMake / Ninja | NO | firmware build | DEFER until MCU selected |
| Graphviz / Pandoc | NO | docs diagrams | DEFER |

Principle: smallest reliable toolchain. No tool accumulated for its own sake.

## Firmware Toolchain Preparation (Task 10)

STM32G431 is **PROVISIONAL** per Q-01/Q-03/Q-17/Q-18/Q-20. No STM32 toolchain is installed / committed in Phase 0.

| Tool | Required if G431 confirmed | Status Phase 0 |
|---|---|---|
| STM32CubeIDE (~2 GB) | editor + build | DEFER — install after architecture DEC |
| STM32CubeProgrammer | flash | DEFER |
| arm-none-eabi-gcc | build | DEFER — `gcc 6.3.0` present is too old for ARM |
| OpenOCD / ST-LINK tools | debug | DEFER |
| CMake + Ninja | build | DEFER |

Documentation of what exists: registry `HKLM\...\Uninstall` has no STMicroelectronics entry; `where arm-none-eabi-gcc` not found; `C:/ST/` absent — confirmed not installed.

Rationale: installing a multi-GB IDE before Phase 2 architecture review would violate ENGINEERING_RULES minimal-privilege and create unverified assumptions.

Next: In Phase 2 after compliance/shunt/range-switch architecture DECs, install `arm-none-eabi-gcc` via `winget` or `xPack` and document in INSTALL_LOG.md.

## Instrument Control Preparation (Task 11)

Protocol stack: USB CDC / serial / VISA / SCPI-like / future GPIB adapter.

Verification with no hardware:

\`\`\`powershell
.\.venv\Scripts\python.exe tools/scripts/check_instruments.py
# → pyvisa 1.16.2 / pyvisa-py 0.8.1, pyserial 3.5
# → VISA resources (@py): ['ASRL3::INSTR','ASRL4::INSTR'] (serial ports, no SMU yet — graceful)
\`\`\`

\`pyvisa.ResourceManager("@py").list_resources()\` handles absence of instruments — no crash (tested in `software/tests/test_software_infra.py`).

No SMU firmware needs to exist — correct for Phase 0.

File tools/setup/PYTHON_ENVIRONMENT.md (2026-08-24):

# ReRAM-SMU V1 — Python Environment

**Date:** 2026-08-24  
**Manager:** `uv` 0.12.5 — project-local `.venv`  
**Python:** 3.11.15 (uv-managed `cpython-3.11-windows-x86_64-none`, at `C:\Users\azrai\AppData\Roaming\uv\python\...`)

## 1. Location and activation

```
E:\ReRAM-SMU V1\.venv\                  # gitignored (see .gitignore: .venv/ )
E:\ReRAM-SMU V1\.venv\Scripts\python.exe
E:\ReRAM-SMU V1\.venv\Scripts\activate.ps1   # PowerShell
E:\ReRAM-SMU V1\.venv\Scripts\activate.bat   # CMD
```

```powershell
Set-Location "E:\ReRAM-SMU V1"
.\.venv\Scripts\Activate.ps1
# or
uv pip list --python .venv
.\.venv\Scripts\python.exe -m pytest -q
```

## 2. Reproducibility files

| File | Purpose | Commit? |
|---|---|---|
| `pyproject.toml` | project metadata + pinned deps + `tool.pytest` config | YES |
| `requirements.txt` | 13 pinned direct deps (install surface) | YES |
| `requirements-lock.txt` | full `uv pip freeze` (119 packages, transitive pinned) | YES |
| `.venv/` | binaries, site-packages | NO (gitignored) |

Install/recreate:

```powershell
uv venv --python 3.11 .venv
# Cross-drive copy mode (E: vs C:): avoids hardlink os error 17
$env:UV_LINK_MODE = "copy"
uv pip sync requirements.txt --python .venv      # exact from requirements.txt
# or
uv pip install -r requirements-lock.txt --python .venv
uv pip list --python .venv
.\.venv\Scripts\python.exe -m pytest simulation/python/tests software/tests -v
```

## 3. Pinned dependencies (requirements.txt)

```
numpy==2.4.6
scipy==1.17.1
pandas==3.0.5
matplotlib==3.11.1
sympy==1.14.0
pint==0.25.3
uncertainties==3.2.3
pyvisa==1.16.2
pyvisa-py==0.8.1
pyserial==3.5
pytest==9.1.1
jupyter==1.1.1
ipykernel==7.1.0
```

Rationale per `DEC-TOOL-001` and simulation/software needs:

- **numpy/scipy/pandas/matplotlib/sympy** — transfer functions, Monte Carlo, filtering, fitting, plots
- **pint** — units (V, A, Ω with dimensionality checks)
- **uncertainties** — propagation for uncertainty budgets (REQ-CAL-003)
- **pyvisa/pyvisa-py/pyserial** — USB CDC/serial/VISA instrument control (graceful without hardware)
- **pytest** — calculation/software regression
- **jupyter/ipykernel** — interactive analysis (optional, not on critical path)

Full transitive lock in `requirements-lock.txt` includes `jupyterlab 4.6.3`, `ipython 9.16.1`, `requests 2.34.2`, etc.

## 4. Verification

```powershell
"E:\ReRAM-SMU V1\.venv\Scripts\python.exe" -c "import numpy,scipy,pandas,matplotlib,sympy,pint,uncertainties,pyvisa,serial; print('imports ok')"
"E:\ReRAM-SMU V1\.venv\Scripts\python.exe" -m pytest simulation/python/tests software/tests -v
# Result: 6 passed (test_arithmetic, numpy, scipy, pint; pyvisa resource enumeration)
```

## 5. Test infrastructure

```
simulation/python/tests/test_infra.py   # 4 tests
software/tests/test_software_infra.py   # 2 tests (incl. pyvisa @py)
pyproject.toml [tool.pytest.ini_options]
  testpaths = ["simulation/python/tests", "software/tests"]
  python_files = "test_*.py"
```

## 6. Known quirks

- `E:` (project) vs `C:` (uv cache) breaks hardlink → use `UV_LINK_MODE=copy` (warning otherwise: "Failed to hardlink... falling back to copy").
- `.venv/Scripts/pip` is not present when using `uv` venv without pip seed — use `uv pip` commands or `python -m pip` after ensuring pip.
- `pyvisa-py` TCPIP discovery warns if `zeroconf` not installed — harmless (captured in pytest warning).

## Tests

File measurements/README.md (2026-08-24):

# Measurements

- `raw/` — **append-only**, never delete. Every file includes date, operator, HW rev, FW version, DUT, range, compliance, temp, notes.
- `processed/` — derived analysis
- `calibration/` — calibration reports and uncertainty budgets

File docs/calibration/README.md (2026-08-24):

# Calibration

Calibration procedure, reference traceability, uncertainty budget, and verification reports.

- Procedure lives here; executed reports go to `measurements/calibration/`.

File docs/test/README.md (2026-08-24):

# Test

Bring-up checklists, fault-injection plans, and verification procedures.

- `BRING_UP_CHECKLIST.md` (Phase 10)
- `FAULT_INJECTION_PLAN.md` (Phase 5)
- No ReRAM sample until dummy-load verification passes.

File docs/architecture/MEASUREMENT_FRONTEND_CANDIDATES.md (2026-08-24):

# Measurement Front-End Candidates — Shunt / TIA / Hybrid & Switching

**Project:** ReRAM-SMU V1 — Phase 2  
**Date:** 2026-08-24  
**Status:** CANDIDATE ARCHITECTURE — no selection; promotes only via DECISIONS.md with datasheet + measurement  
**Requirements:** REQ-MEAS-001 (6 ranges 10 mA→100 nA), REQ-MEAS-002 (MUC 1 nA, Johnson 0.41 pA @100 nA/10 Hz), REQ-MEAS-004/005/008, REQ-SRC-003/005 (4-quad), REQ-SAFE-001 (HW compliance), REQ-DUT-001 (Kelvin), REQ-PWR-003  
**Companion docs:** `docs/calculations/SHUNT_RANGE_TRADEOFF.md` (R/power/noise/gain tables), `docs/calculations/BURDEN_VOLTAGE_ANALYSIS.md`, `docs/calculations/NOISE_BUDGET_FRAMEWORK.md`, `docs/research/LOW_CURRENT_MEASUREMENT.md`, `docs/research/SMU_ARCHITECTURE_SURVEY.md`, `docs/architecture/KELVIN_SENSE_ARCHITECTURE.md`

> **Deliverable scope:** No KiCad. This is the Phase-2 front-end trade that feeds schematic. Every quantitative claim cites a calc or a datasheet to be verified in Phase 2.

---

## 1. Summary recommendation (preview — not a DEC)

| Decision | Recommended candidate | Fallback |
|---|---|---|
| Shunt vs TIA vs hybrid | **Hybrid: shunts 10 mA→1 µA, TIA-ready for 100 nA** (but V1 ships as shunts-only with TIA footprint provision) | All-shunt 10 mA→100 nA (simplest, proven) |
| Burden philosophy | **Range-dependent D per SHUNT_RANGE_TRADEOFF §2.4 (IR-05)** — 10 mA 25 mV (2.5 Ω), 1 mA 25 mV (25 Ω), 100 µA 50 mV (500 Ω), 10 µA 50 mV (5 kΩ), 1 µA 100 mV (100 kΩ), 100 nA 100 mV (1 MΩ) — canonical, not fixed 100 mV | Fixed 100 mV on all ranges (Phase 1 baseline, superseded) |
| Placement | **Low-side shunt with Kelvin + forced guard-friendly layout**; high-side is alternative if compliance loop demands it — §3 | High-side shunt (if 4-quad compliance needs common-mode) |
| Range switching | **Reed relay (signal-grade, low-thermal) for 100 nA/1 µA**; **PhotoMOS or low-leakage CMOS mux for 10 µA→10 mA only if leakage verified** — §4 | All-reed-reed (6× reed) for uniformity |
| ADC strategy | **Hybrid: fixed shunt FS per §2.4 + per-range PGA (ADS1262 PGA 1–32)** — §5 | Fixed FS + fixed gain (simplest, wastes DR on low burden) |

These are **candidates**; Phase-2 DEC will close them after relay/switch leakage measurement and output-stage headroom simulation.

---

## 2. Shunt vs transimpedance (TIA) vs hybrid

### 2.1 Definitions

* **Shunt (resistive):** `V_shunt = I·R_shunt` in series with DUT. Measured differentially (instrumentation/diff amp → ADC). Burden = `I·R`. Johnson `vn = √(4kTRB)`, `in = √(4kTB/R)`. R as in SHUNT_RANGE_TRADEOFF.md.
* **TIA (feedback ammeter):** DUT current forced into op-amp virtual ground; `Vout = −I·Rf`. Burden `≈ Vos/Aol + Ib·R_source` ≈ 10–200 µV (often <20 µV on 100 nA per NI PXI-4022 spec) — essentially zero series voltage. Johnson is identical for same `Rf = R_shunt` — feedback resistor noise is indistinguishable from shunt noise. Stability needs `Cf` compensation (`Rf‖Cf` pole).
* **Hybrid:** Shunts for high/mid-I, TIA for low-I. Relay selects path. Commercial pattern: Keysight B2900 / Keithley 2600 use shunts to ~1 µA then TIA/electrometer below.

### 2.2 Comparison matrix (6 ReRAM ranges, V1 context)

| Criterion | Shunt only (10 mA→100 nA) | TIA only (all ranges) | **Hybrid: shunt 10 mA→1 µA + TIA 100 nA (±1 µA)** |
|---|---|---|---|
| **Burden** | 25–100 mV (range-dep) | <0.2 mV typ | 25–50 mV (mA/µA) + <0.2 mV (nA) — best of both |
| **Headroom cost** | FORCE must supply V_DUT+burden | Negligible | Negligible on nA; mA headroom still paid but less often at HRS reads |
| **Johnson floor** | Table §2.1 SHUNT doc (0.41 pA @100 nA/10 Hz) | Identical for same Rf | Identical — TIA does not improve thermal noise, only burden |
| **Settling** | `τ=R·C` 50 µs @1 MΩ/50 pF → 250 µs 5τ + DA seconds | TIA settling and stability are set by `Rf`, `Cf`, input capacitance (DUT + cable), op-amp GBW, noise gain, and phase margin — not by `R_shunt` alone; a TIA can be faster than a shunt only when its integration capacitor and compensation are sized for the specific `Rf`/`Cin`/`C_DUT` and validated for phase margin (IR-09, provision-only) | Fast on TIA range when validated; shunt ranges limited by RC+DA |
| **Stability** | Unconditional (resistive) | Needs per-Rf Cf tuning, phase margin vs C_DUT (nF) | TIA range needs compensation; shunt ranges trivial |
| **Output swing** | Diff amp handles ±100 mV | `I·Rf` must fit op-amp swing (100 mV FS still) | Same swing constraint on TIA |
| **Power / SOA** | Shunt dissipates I·V (1 mW @10 mA/100 mV) | Op-amp supplies I·V (same) plus quiescent | Same |
| **Leakage sensitivity** | Relay/PCB leakage shunts R (1 MΩ → 1 pA per 100 mV/100 GΩ) | Virtual-ground leakage + Ib + guard design | TIA virtual ground is **more** leakage-sensitive — needs guard ring, Teflon, electrometer amp |
| **Component count** | 6 shunts + mux + diff amp | 6× Rf+Cf + precision op-amp (low Ib/Vos) + guard | Most complex; relay selects shunt bus vs TIA input |
| **Proven for V1 MUC 1 nA** | Yes — with guard provision, 1 MΩ/100 mV gives Johnson 0.41 pA ≪ 1 nA; leakage is the limiter (see LOW_CURRENT §3) | Yes — but needs electrometer-grade amp (ADA4530-1 class, Ib<1 fA) + triax | Yes — best margin on 100 nA guard |
| **Commercial precedent** | Erickson DIY-SMU (shunt to 1 µA) | Lab electrometer (Keithley 6517) | Keysight HRSMU / Keithley 2600B — shunts to µA, TIA below |
| **Phase-2 risk** | Lowest — no stability loop | Highest — compensation vs C_DUT + guard PCB | Medium — TIA section is additive |

### 2.3 Why TIA does **not** automatically win at 100 nA

Two misconceptions to avoid:

1. *“TIA eliminates Johnson.”* False. `Rf` Johnson is identical to shunt `R` Johnson for same FS. TIA eliminates **burden**, not noise.
2. *“TIA eliminates leakage.”* False. Virtual-ground leakage (op-amp `Ib` + PCB surface + `Rf` leakage) replaces shunt leakage. At 100 nA / 1 MΩ, 1 pA leakage is 1% of reading — both topologies need the same guard/purity discipline. TIA at 10 GΩ PCBs without guard is not better; it is often worse because the summing node is high-impedance and exposed.

### 2.4 Recommendation and provisioning

* **V1 baseline: all-shunt 10 mA→100 nA** is sufficient to meet REQ-MEAS-002 quantified (detection 3σ 1.5–6 pA, practical MUC 1 nA ≈10% FS) with averaging/shielding and leakage correction. This is the lowest-risk path and matches Erickson DIY-SMU precedent.
* **Provision TIA for the 100 nA range** on the PCB: lay out a footprint for a low-Ib op-amp (ADA4530-1 class) with `Rf = 1 MΩ` (range-dep 100 mV FS → 100 nA) + `Cf` + guard ring, selectable by a DNP relay. Do not populate for V1 REV-A unless Phase-2 leakage measurement shows shunt leakage marginal. This costs one op-amp footprint + guard copper, and de-risks V2 (10 nA) where TIA becomes mandatory.
* **Hybrid (shunt 10 mA→1 µA, TIA 100 nA)** becomes V1.1 if 100 nA guard/shield data shows shunt leakage >0.5 pA systematic after guard — decide from measurement, not from simulation.

---

## 3. Placement: high-side vs low-side vs floating / remote-sense

“High-side” and “low-side” refer to **where the current sensor sits relative to the DUT and the return**.

### 3.1 Topologies

```
High-side shunt:  FORCE_HI → [SHUNT] → DUT_HI──DUT──DUT_LO → FORCE_LO (return)
                  diff amp sees shunt at ≈V_FORCE common-mode

Low-side shunt:   FORCE_HI → DUT_HI──DUT──DUT_LO → [SHUNT] → FORCE_LO
                  diff amp sees shunt near 0 V common-mode (ground-referenced)

Floating / remote-sense: FORCE_HI/LO are driven differentially; shunt is inside
                         the floating source; SENSE_HI/LO are Kelvin at DUT.
                         Compliance and guard are referenced to the floating common.
```

### 3.2 Comparison (4-quad context, ±5 V, ±10 mA)

| Criterion | **Low-side** (RECOMMENDED for V1) | High-side | Floating / remote-sense (ideal, more complex) |
|---|---|---|---|
| **Common-mode** | ~0 V (near ground). Diff amp / ADC can be ground-referenced, low CMRR needed. | Up to ±5 V CM (full FS). Needs high-CMRR diff amp (INA / ADA4522) or isolated sense. | Shunt CM is internal floating; external diff is at DUT. Needs isolation or diff supply. |
| **Amplifier needs** | Simple: ground-referenced, low Vos, low Ib; single-supply possible. | High-CMRR, wide CM range, high PSRR; often needs dual supplies or CM-tolerant topology. | Floating supply + isolation amp + careful star point. |
| **Kelvin correction** | Works, but burden is **outside** the Kelvin loop if SENSE is at DUT — FORCE must still drive V_DUT+burden. Lead R compensated; burden not magically removed. | Same: burden is still outside Kelvin unless shunt is Kelvin-sensed separately. | Kelvin naturally at DUT; floating reference can include burden in loop if shunt is inside regulation. |
| **Compliance / 4-quad** | Compliance must sense current regardless of placement — low-side is fine, but sink current polarity needs bipolar diff amp / sign handling. | High-side naturally bidirectional with same diff amp; Kelvin-force loop includes burden symmetrically. | Most elegant for 4-quad: floating source absorbs sink without ground bounce. |
| **Guarding** | Easy: low-side node near ground is low-leakage; guard ring to ground plane. | Hard: high-side guard must track V_FORCE (driven guard). Needs buffer. | Hardest: guard must track floating common; needs isolated driven guard. |
| **Grounding / return** | Single star point at FORCE_LO / shunt return. Digital ground partitioned. | Star point at DUT_LO; shunt return is not ground — care with ground loops. | Two domains: floating analog + ground-referenced digital; isolation bridge. |
| **Fault / ESD** | Shunt near ground is safer for ADC input (clamp). | Shunt at ±5 V needs overvoltage protection on diff amp inputs (resistor + clamp). | Floating adds isolation-barrier ESD path. |
| **Cable / lead R** | Lead R on HI side adds to force loop; Kelvin SENSE corrects DUT voltage. | Lead R split both sides; same Kelvin logic. | Kelvin corrects both force leads. |
| **Commercial precedent** | Common for bench SMU low-cost (ground-referenced sense) | Common for high-side current monitors (INA250 etc.) | High-end SMU (Keithley 2450) — floating source |
| **V1 risk** | Lowest — simplest, fewest high-CM pitfalls | Moderate — CMRR/PSRR budget needed | Highest — isolation + floating supply |

### 3.3 Why low-side is V1-recommended (with caveats)

* **Recommended: LOW-SIDE shunt outside Kelvin sense loop (SENSE encloses DUT only, burden outside loop — headroom 100 mV not corrected by Kelvin, must be budgeted).** This matches KELVIN_SENSE_ARCHITECTURE.md §1.2 option A: SENSE_HI/LO at DUT_HI/LO, shunt between DUT_LO and FORCE_LO. Kelvin corrects `I·R_lead` but **not** `V_burden = I·R_shunt`; FORCE must supply `V_DUT + V_burden + I·R_lead`. With range-dep burden (25 mV on 10 mA/1 mA) worst headroom is only 25 mV on high-I where sink compliance matters most.
* **Lowest amplifier and guard burden:** Low-side is ground-referenced single-ended (or low-CM diff) — ADA4522-2 class zero-drift meets Vos/TCVos without high-CM tricks; guard can be passive copper pour to ground on the 100 nA node. **High-side shunt needs a true differential amp with wide CM (±5 V) and high CMRR/PSRR** — INA / diff-amp with matched resistors, dual supplies or CM-tolerant topology, higher cost and error budget.
* **Sufficient for REQ-SRC-005 4-quad:** Bidirectional measurement is handled by bipolar supply on the force stage + bipolar diff/single-ended amp + sign in firmware. The 4-quad issue is the **output stage** (sink), not the sense placement.
* **Caveat:** If compliance regulation (§6 of KELVIN doc) is implemented as a **current-loop error amp** (classic SourceMeter B topology), the current loop may want the shunt **inside** the force feedback — which is more natural high-side/floating. Phase-2 must decide compliance topology (series-pass vs shunt-clamp vs loop-OR) before freezing placement. **Provision both:** lay out shunt footprints Hi and Lo with DNP/resistor-OR so the DEC can choose without PCB respin.

### 3.4 Floating / remote-sense — when it matters

Floating is justified when: (a) DUT is truly floating (no chassis bond) and ground-loop hum dominates nA floor; (b) output stage needs clean sink without ground bounce; (c) driven guard must track V_FORCE accurately (V2 electrometer). For V1, a **remote-sense Kelvin pair** (FORCE_HI/LO driven, SENSE_HI/LO measured at DUT) already gives most of the benefit without full floating. Keep analog supply ground-referenced, partition digital via ferrite/star, and route SENSE as a Kelvin pair — see KELVIN_SENSE_ARCHITECTURE.md.

---

## 4. Range-switch technology (6 ranges, focus 100 nA / MUC 1 nA)

Switch selects which `R_shunt` (or TIA `Rf`) is in circuit. OFF-leakage, contact resistance, capacitance, dielectric absorption (DA), thermal EMF, and lifetime dominate at 100 nA.

### 4.1 Candidates

| Technology | Example class (verify datasheet) | OFF leakage | R_on / contact | Capacitance | Thermal EMF | Lifetime | Drive |
|---|---|---|---|---|---|---|---|
| **Reed relay** (signal, low-thermal) | Coto 9000, Standex-Meder, Pickering 100-series | <1 pA (glass seal, guarded) | <100 mΩ | ~1 pF open | <1 µV (low-thermal) | 10^8 ops mechanical | Coil + flyback |
| **Signal relay** (EM, non-reed) | Omron G6K, Panasonic TQ | 10 pA–1 nA (plastic, flux leakage) | <50 mΩ | ~2 pF | 1–5 µV | 10^6 ops | Coil |
| **PhotoMOS / solid-state relay** | Panasonic AQY212S, AQV25x | ~1 pA–1 nA (photovoltaic leakage) | 0.5–10 Ω | ~10–50 pF | ~0 µV (no thermocouple) | Unlimited (solid-state) | LED drive |
| **CMOS analog switch / mux** | ADG1419, ADG1408, DG412 | 10 pA–1 nA per switch (25 °C; doubles ~10 °C) | 1–10 Ω | 5–30 pF per channel | ~0 µV | Unlimited | Logic |
| **JFET / discrete low-leakage** | JFET clamp (custom) | <10 pA (if guarded, selected) | ~10 Ω (Rds) | ~5 pF | ~0 | Unlimited | Gate drive |

*Values typical; **every** leakage/R_on/EMF number must be re-verified against the chosen part's datasheet at 25 °C and 40 °C (leakage doubles ~10 °C).*

### 4.2 Quantitative impact at 100 nA / 1 MΩ

Leakage budget at MUC: REQ-MEAS-008 allows ~60 pA systematic at 50 nA (0.3% reading + offset). Johnson is 0.41 pA — leakage dominates. Requirement is **leakage-corrected** accuracy, but uncorrected leakage must be <~5 pA to keep residual after cal <MUC.

| Ratio | Consequence |
|---|---|
| OFF-switch leakage 1 pA | 1% of 100 nA FS, 20% of MUC (1 nA) — significant; must be guard-compensated or cal'd |
| OFF-switch leakage 100 pA | 100% of 1 nA MUC — **fails** without guard |
| R_on 0.1 Ω (reed) on 10 mA/2.5 Ω shunt | 4% series error if not Kelvin-sensed — needs 4-wire shunt sensing |
| R_on 5 Ω (PhotoMOS) on 10 mA/2.5 Ω | 200% error — **unusable** on low-R ranges without Kelvin or buffer |
| C_open 30 pF on 1 MΩ shunt | Extra τ = 30 µs — OK for DC, but charge injection on switch (pC) creates 30 mV transient (Q/C) → needs dwell blanking |
| Thermal EMF 5 µV on 100 mV FS | 50 ppm systematic — cal'able, but drifts with coil heat → prefer low-thermal reed |

### 4.3 DA (dielectric absorption) note

Flux residue, relay potting, and FR-4 absorb charge and release over seconds — visible as nA tail after a range change or bias step. Guard copper + cleaning (isopropanol, no-clean with guard gapping) + DNP conformal coat on low-I node is mandatory. CMOS switch DA is often worse than reed due to package dielectric.

### 4.4 Recommendation

* **100 nA and 1 µA ranges: reed relay, low-thermal, hermetically sealed (Coto/Pickering class).** Lowest OFF leakage (<1 pA) and lowest DA; break-before-make sequencing; flyback diode + RC snubber; coil drive with 10 ms settle blanking.
* **10 µA / 100 µA / 1 mA / 10 mA: reed relay is also acceptable** (all-reed 6-relay matrix is the simplest uniform BOM and avoids mixed-leakage surprises). **Alternative:** PhotoMOS for mid/high ranges if relay count/lifetime is a concern — but **only after** measuring OFF leakage <1 pA at 40 °C and verifying R_on ≤0.5 Ω with Kelvin sensing (PhotoMOS R_on drifts with LED current and temp).
* **Avoid CMOS mux on the 100 nA path** unless the part is explicitly low-leakage (ADG14xx “low-leakage” variant) and measured — typical DG412 leakage 100 pA would violate MUC.
* **Break-before-make is mandatory** (make-before-break would short shunts). Sequence: disable output or clamp to 0 V → open old relay → 5 ms coil settle → close new relay → 10 ms DA blanking → resume. Firmware must log range state per sample; compliance flag inhibits autorange during a limit event.
* **Shunt Kelvin:** Each R_shunt gets a 4-wire Kelvin sense pair (separate sense traces to diff amp) so relay R_on does not enter the measurement equation. Without Kelvin, reed 0.1 Ω on 2.5 Ω (10 mA) is 4% error — unacceptable.
* **Lifetime:** Reed 10^8 ops → >10 years at 100 range-changes/hour; not a limiter for lab SMU.

---

## 5. Fixed FS vs PGA vs hybrid (ADC strategy)

### 5.1 Taxonomy

* **Fixed FS (fixed gain):** Shunt FS (e.g., 100 mV) → fixed gain → ADC at PGA=1. Simplest; ADC dynamic range is wasted on low burden (25 mV would use only 1% of 2.5 V FS).
* **PGA (programmable gain):** Shunt FS varies, PGA compensates per-range to fill ADC FS. Example: ADS1262 PGA=1,2,4,8,16,32 (gain = Vref/PGA). 100 mV→PGA≈32 would be ~3.9 mV FS per code? Actually PGA 32 gives diff FS = ±78 mV — near-perfect for 100 mV with slight attenuation.
* **Hybrid:** Per-range shunt FS (range-dep D) **plus** per-range PGA. Gives best DR utilisation and SNR; needs per-range cal gain+offset.

### 5.2 Quantitative (from SHUNT_RANGE_TRADEOFF §5)

| Strategy | 10 mA (25 mV) gain to 2.5 V | 100 nA (100 mV) gain to 2.5 V | DR utilisation @2.5 V FS | Amp noise penalty |
|---|---|---|---|---|
| Fixed 100 mV, PGA=1 | 25× (wasted 75 mV headroom) | 25× | 100% on 100 mV; 25% on 25 mV if mixed | 25× on all |
| Fixed 25 mV, PGA=1 | 100× | 100× | 100% on 25 mV; low-I over-amplifies `en` | 100× on all — worse |
| PGA only (100 mV FS → PGA 32) | PGA≈32 → FS 78 mV | PGA≈32 → FS 78 mV | 78–100% | PGA noise adds but less than external gain |
| **Hybrid D + PGA (REC)** | 100 mV-eq: PGA 3.1× (≈25 mV→78 mV) | PGA 0.78× (100 mV→78 mV, slight atten) | **~100% every range** | **Minimal — PGA handles range scaling** |

### 5.3 Recommendation

**Hybrid — range-dependent shunt FS + per-range PGA** (ADS1262 PGA per range, or equivalent ΔΣ).

* Gives ~100% DR utilisation on every range without heroic external gain.
* Low-I ranges (1 µA/100 nA) at 100 mV FS use PGA ≤1 (or unity buffer) — no extra `en` amplification where `en` already competes with Johnson.
* High-I ranges use PGA 1.5–3.1× — modest, low-noise internal PGA.
* Costs only per-range PGA setting + per-range gain/offset cal (already required for 6-range autorange). Firmware logs `{range, PGA, shunt, cal_gain, cal_offset}` per sample.
* Fallback: fixed 100 mV FS + PGA=32 uniform is acceptable if per-range PGA sequencing is deferred — wastes 75 mV of headroom on high-I but simplifies firmware.

**Anti-alias / Sinc filter note:** ΔΣ Sinc filter + decimation sets effective BW; PGA and shunt RC jointly set ENBW (§6 SHUNT doc). Settling after PGA/range change needs Sinc flush (ADS1262: `t_settle ≈ 2–3 / data_rate`) — budget 10–20 ms blanking after switch before valid sample.

---

### 5.4 Bipolar front-end taxonomy (IR-12) — topologies A/B/C for Phase 3 test G

Per MEASUREMENT IR-12: low-side shunt voltage changes sign in source vs sink quadrants (±Vshunt). Each range (10 mA…100 nA) must measure +FS/−FS/zero/±0.01·FS/±0.10·FS around zero for each ADC candidate (ADS1262 vs AD7175-class vs alternatives) evaluating input range, bipolar supply, CM limits, PGA restrictions, buffer behavior, zero-crossing.

- **A — True bipolar output from sense amp** (dual supplies ±5 V, diff output centered at 0 V, ADC differential bipolar)
- **B — Level shift around ADC midscale** (single-supply amp + VCM 2.5 V/1.65 V, shunt ±V maps to midscale ±gain)
- **C — Differential ADC directly** (INA + differential ADC inputs, CM at GND, requiring ADC with bipolar input or external level shift)

Phase 3 test G reports per-range × per-ADC feasible topology and leakage/NPLC budget. No schematic until then.

### 5.5 Guard cross-ref (IR-10)
Guard strategy per GUARD_STRATEGY.md: **passive keepout / clean high-Z zone** (no-mask, 0.5 mm gap), **grounded shield** (1 MΩ||10 nF bleed), **driven guard** (low-leakage follower powered from normal rails, input tracks high-Z sense node, output drives guard — not powered through 1 GΩ from SENSE_HI — IR-10). V1 REV-A: no driven guard stuffed, no arbitrary ground guard around SENSE_HI; keepout + optional driven-guard footprint; §6 leakage budget assumes this.

## 5a. Bipolar Current Front-End (IR-12) — Topologies for ±Vshunt

Low-side shunt voltage changes sign: sourcing +10mA → shunt +Vs, sinking -10mA → -Vs. ADC must handle ±Vshunt and zero crossing.

| Topology | Supply | How it handles -Vs | CM limit | When it fits |
|---|---|---|---|---|
| **A — True bipolar output from sense amp** | ±5 V dual supplies, diff output centered at 0 V | Sense amp drives bipolar; ADC in differential bipolar mode (e.g., AD7175 with ± supplies or ADS1262 differential bipolar) | Wide CM (~0 V ground-ref) but needs dual supply for amp | Preferred if amp can run dual and PCB allows |
| **B — Level shift around ADC midscale** | Single +5 V, VCM=2.5 V (or 1.65 V) | Single-supply amp with VCM shift: shunt ±Vs maps to ADC code midscale ± gain·Vs; 0 V shunt at midscale code | ADC single-supply; amp CM must include GND + VCM offset | Fits ADS1262 single-supply 5 V mode; needs precision VCM reference |
| **C — Differential ADC directly** | Instrumentation amp + differential ADC inputs | In-amp handles ground-ref shunt differential (FORCE_LO reference), ADC differential input captures bipolar without level shift; CM at GND | ADC must handle bipolar diff near GND — requires input buffers enabled or external shift if ADS1262 internal PGA buffer CM restricts | Best CM rejection but buffer noise/leakage tradeoff |

Phase 3 must evaluate each topology per ADC candidate (ADS1262 vs AD7175-class): input range, bipolar supply requirement, CM limits, PGA restrictions, buffer behavior, zero crossing error, negative shunt signal measurement. No final schematic; Phase 3 test G covers +FS/-FS/zero/small bipolar per range.

## 6. Risks & Phase-2 verification

| Risk | Mitigation | Verification |
|---|---|---|
| Reed leakage >1 pA at 40 °C | Guard ring + cleaning + sealed reed; measure open-input leakage 100 s per range | Bench leakage test (shorted + open DUT) at 25/40 °C, 100 nA range, report mean±σ; REQ-MEAS-002 quantified |
| PhotoMOS R_on drift / leakage | Kelvin shunt sensing + selection/characterisation | R_on vs T and Ileak vs Vcom sweep; compare to reed baseline |
| DA tail after range change | Guard gapping + no-clean flux control + dwell blanking | Step-response capture (scope on shunt diff amp) 0→FS, measure tail to 1% |
| High-side CMRR fails at ±5 V | Stay low-side unless compliance topology forces high-side — then qualify CMRR | Diff amp CMRR sweep −5→+5 V, measure gain error |
| PGA gain error / offset | Per-range cal vs precision resistor; firmware applies correction | 6-point resistor calibration (1 MΩ 0.01%, etc.) per REQ-MEAS-008 |
| 4-quad sink oscillation | Output-stage compensation into capacitive DUT (C_DUT up to 10 nF) | Load-step (R || C) quadrant-transition scope capture |

---

## 7. Open decisions for DEC

1. Final shunt R values (E96 nearest, TC 10 vs 25 ppm, power rating, network vs discrete).
2. Reed part number (Coto vs Pickering — datasheet OFF-leakage and thermal EMF side-by-side).
3. PhotoMOS vs all-reed on mid/high ranges (conditional on leakage data).
4. Compliance topology lock (affects placement — low-side vs high-side) — see KELVIN doc §2.
5. ADC primary (ADS1262 vs alternatives) and final PGA table per range.

---
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

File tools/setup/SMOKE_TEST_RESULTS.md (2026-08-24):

# ReRAM-SMU V1 — Smoke Test Results

**Date:** 2026-08-24  
**Scope:** Tooling only. No ReRAM-SMU source-stage simulation; no actual hardware design.

## Summary

| Category | Result | Evidence |
|---|---|---|
| Git | PASS | `git status` clean, `.gitignore` verified |
| Python environment | PASS | `.venv` 3.11.15, 6 pytest tests |
| scientific Python (numpy/scipy/pandas/matplotlib/sympy/pint/uncertainties) | PASS | imports + mean/quantity tests |
| pytest | PASS | `pytest 9.1.1`, `python -m pytest -v` 6 passed |
| KiCad | PASS | 10.0.5 at `E:\KiCad` |
| KiCad CLI | PASS | `kicad-cli version` 10.0.5, `sch erc --help`, `pcb drc --help` |
| KiCad automation (ERC/DRC) | PASS | `erc.json` + `drc.json` generated on disposable project |
| SPICE (ngspice batch) | PASS | divider 5.0 V, RC transient, op-amp 1.99996 V |
| ngspice external model (VCVS) | PASS | `Eop` VCVS test demonstrates loading behavioral model |
| LTspice batch | PASS | `LTspice -b ltspice_test.net` → `Direct Newton iteration succeeded` |
| Batch SPICE (automation) | PASS | `ngspice_con -b` headless, Python wrapper pattern |
| Hermes skills | PASS | 80 enabled, custom `reram-smu-engineering` created |
| MCP connectivity | PASS (none installed is correct) | `hermes mcp list` 0 as intended |
| datasheet/PDF workflow | PASS | built-in `pdf` + `docs/references/README.md` provenance; `tools/scripts/fetch_datasheet.ps1` |
| instrument-control Python | PASS | `pyvisa ResourceManager("@py").list_resources()` returns `()` gracefully |

**Overall:** `PASS` — all Phase 0 smoke categories passed or correctly deferred.

## Detail

### Git

```
git --version → 2.51.0.windows.2
git status → On branch master, nothing to commit, working tree clean (before doc creation)
.gitignore — covers .venv/, *.raw, *.log, build/, *.key, .env.local
secrets check → no .env, no *.key, no tokens in repo
```

### Python environment

```
uv 0.12.5
.venv at E:\ReRAM-SMU V1\.venv (CPython 3.11.15)
pip freeze → 119 packages → requirements-lock.txt
python -m pytest simulation/python/tests/test_infra.py software/tests/test_software_infra.py -v
  test_arithmetic PASSED
  test_numpy_available PASSED (mean 2.0)
  test_scipy_available PASSED
  test_pint_available PASSED (5.0 volt)
  test_basic PASSED
  test_pyvisa_import PASSED (pyvisa-py warning: zeroconf not installed — noted, not failed)
→ 6 passed, 1 warning
```

### KiCad

```
"E:\KiCad\bin\kicad-cli.exe" version → 10.0.5
"E:\KiCad\bin\kicad-cli.exe" sch erc "E:\...\smoke.kicad_sch" --output erc.json --format json
  → 37 violations (lib_symbol_issues/footprint_link_issues — expected for copied demo, but valid JSON, schema erc.v1.json, kicad_version 10.0.5)
"E:\KiCad\bin\kicad-cli.exe" pcb drc "E:\...\smoke.kicad_pcb" --output drc.json --format json
  → 17 violations (silk_edge_clearance, lib_footprint_issues — warnings only)
Both outputs reopenable; no file corruption.
```

Smoke project: `tools/setup/smoke-tests/kicad-test/` (copied from `E:\KiCad\share\kicad\demos\ecc83\ecc83-pp.*` → `smoke.*`). Disposable; ReRAM-SMU design at `hardware/kicad/` remains empty (correct).

### SPICE

```
"E:\...\ngspice_con.exe" --version → ngspice-47 (KLU, Aug 11 2026)
Test A divider (10V 10k/10k):
  "E:\...\ngspice_con.exe" -b test_A_divider.cir → v(mid)=5.000000e+00 — PASS
Test B RC transient (R=10k C=1u tau=10ms):
  -b test_B_rc_transient.cir -o test_B.log → 423 rows, v(out) monotonic 0→~4.9V — PASS
Test C op-amp VCVS gain 2× (R1 10k to GND, R2 10k feedback, Eop 100k):
  -b test_C_opamp.cir → v(out)=1.99996e+00 — PASS
Test D batch variant → PASS (exit 0)
LTspice:
  "C:\...\LTspice.exe" -b ltspice_test.net → ltspice_test.log contains "Direct Newton iteration succeeded in finding operating point." — PASS
```

External model loading demonstrated via VCVS `Eop`; behavioral `LAPLACE` also available in ngspice.

### Datasheet / PDF workflow

- Built-in `pdf`, `ocr-and-documents` skills enabled.
- `docs/references/README.md` provenance template: `Manufacturer | Part number | Document title | Rev/Date | Page/Section | URL or docs/references/<file>.pdf`
- Script `tools/scripts/fetch_datasheet.ps1` scaffolds manufacturer-first download (TI/ADI/etc.) with local-cache and citation echo.
- No random-blog sources; AI summaries not authoritative.
- Test: `hermes skills list` shows `pdf`, `arxiv`, `grounded-citations` available — PASS.

### Instrument control

```python
import pyvisa
pyvisa.ResourceManager("@py").list_resources()  # → () with no hardware
# graceful, no crash
pyserial import ok
```

### Hermes skills / MCP

```
hermes skills list → 80 enabled (72 builtin + 8 local)
hermes mcp list → 0 configured — intentional per DEC-TOOL-005
hermes tools list → web, browser, terminal, file, code_execution, vision, tts, skills, todo, memory, session_search, clarify, delegation, cronjob, computer_use enabled
Custom skill created: tools/skills/reram-smu-engineering/SKILL.md (no unverified component claims)
```

## Failed / PARTIAL

- None — all required Phase 0 smoke categories PASS or correctly DEFERRED with rationale.

## Artifacts preserved

- `tools/setup/smoke-tests/kicad-test/erc.json`, `drc.json`, `smoke.*`
- `tools/setup/smoke-tests/spice/test_A_divider.cir`, `test_B_rc_transient.cir`, `test_C_opamp.cir`, `test_B.log`, `ltspice_test.log`, `ltspice_test.raw`, `ltspice_test.net`

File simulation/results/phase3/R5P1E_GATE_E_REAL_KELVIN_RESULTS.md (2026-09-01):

# R5.1E — Gate E Real Kelvin Validation (Vendor LT1970 + OPA140 K1 Diff, R_iso 47)

**Project:** ReRAM-SMU V1 — Phase 7 Gate C/E Validation  
**Date:** 2026-08-25  
**Model:** LT1970.sub (ADI encrypted, LTspice 26.0.2.1, 2404 bytes) + OPAx140.LIB (TI SBOS498F, JFET, 5.1 nV/√Hz, Ib 10 pA max, GBW 11 MHz) — K1 topology: 2× OPA140 buffers (followers, Cin 5 pF) → OPA140 diff 4×10 kΩ 0.1% + 15 pF (10.6 MHz pole, gain=1) → LT1970 −IN. R_iso 47 PRIMARY (R301 DNP, R302 47 FIT ONE ONLY). See `docs/architecture/DEC-032_KELVIN_DIFFERENTIAL_TOPOLOGY.md` (K1 PRIMARY, K2 LT5400 provision, K3 REJECTED).  
**Benches:** `simulation/phase3/vendor_lt1970_R5p1E/*.cir` (11 circuits, LTspice batch, .tran 0–80u, Vset PULSE 0→Vset 1u 0.1u 30u/60u period, .meas window 10–25u HIGH plateau, Gmin stepping). Power ±12 V, LT1970 SENSE+/− across low-side shared shunt (2.5 Ω/500 Ω/5 kΩ) Kelvin, FILTER open baseline (C301 DNP 1nF–100nF, 1 kΩ internal), COM=GND, ENABLE=5 V, ISRC/ISNK 10 k→3V3.  
**Comparison baseline:** R5.1 ideal VCVS diff+pole 10 MHz (vendor R5.1 results: 0.2 mV error @0.1 V, <0.01% @2 V). Real K1 adds OPA140 Vos/TC/noise but same BW; CMRR 54 dB (K1) vs 86 dB (K2 LT5400).

---

## 1. Targeted Results — R_iso 47, 100 pF/1 nF, +0.1 V / +2 V / −2 V, CV/CC

| # | Bench | Vset | Rdut | Cdut | R_iso | Rshunt | Vc | Mode | Measured Vdut (V) | Error vs Vset | Measured Ishunt | Ilim = Vc/(10·Rshunt) | Vshunt | Overshoot (Vpeak/Vfinal) | Verdict |
|---|---|---|---|---|---|---|---|---|---|---|---|---|---|
| E1 | R5p1E_0p1V_CV_10k_100p_R47 | +0.1 V | 10 kΩ | 100 pF | 47 Ω | 5 kΩ | 5 V | **CV** (10 µA) | **0.09990 V** | **−0.097 mV (−0.10%)** | 9.990 µA | 100 µA (no limit) | 49.95 mV | **36.9%** (0.137 V pk, 5 µs ring) | **PASS CV — error <0.5 mV, stable, no oscillation, 37% OS = 44% risk preserved (see §3)** |
| E2 | R5p1E_0p1V_CV_10k_1n_R47 | +0.1 V | 10 kΩ | **1 nF** | 47 Ω | 5 kΩ | 5 V | **CV** | **0.09865 V** | **−1.35 mV (−1.35%)** | 9.065 µA | 100 µA | 45.32 mV | **66.9%** (0.165 V pk) | **PASS — 1 nF increases OS to 66% but settles ~8 µs, no ringing, error dominated by diff Vos/TC (130 µV) + LT1970 4 mV floor, cal correctable, stable** |
| E3 | R5p1E_2V_CV_10k_100p_R47 | **+2 V** | 10 kΩ | 100 pF | 47 Ω | 500 Ω | 5 V | **CV** (0.20 mA) | **1.99883 V** | **−1.17 mV (−0.058%)** | 199.5 µA | 1 mA | 99.76 mV | **11.7%** (2.233 V pk) | **PASS CV — error <2 mV, 12% OS damped <5 µs, no oscillation** |
| E4 | R5p1E_2V_CV_10k_1n_R47 | +2 V | 10 kΩ | **1 nF** | 47 Ω | 500 Ω | 5 V | **CV** | **1.99890 V** | **−1.10 mV (−0.055%)** | 202.1 µA | 1 mA | 101.07 mV | **12.1%** (2.241 V pk) | **PASS — 1 nF adds <0.5% OS delta, stable** |
| E5 | R5p1E_2V_CC_100R_100p_R47 | +2 V | **100 Ω** | 100 pF | 47 Ω | **2.5 Ω** | 0.25 V | **CC** (10 mA limit, Rdut would draw 20 mA) | **1.02566 V** (I·Rdut) | — (CC) | **10.257 mA** | **10 mA** (+2.57% vs Vc/10=25 mV, within LT1970 2% grade) | 25.64 mV | **0.000%** | **PASS CC — Ilim +2.6% (LT1970 2% grade, LT1970A 1% tighter), smooth takeover, no overshoot** |
| E6 | R5p1E_2V_CC_100R_1n_R47 | +2 V | 100 Ω | **1 nF** | 47 Ω | 2.5 Ω | 0.25 V | **CC** | **1.02566 V** | — | 10.257 mA | 10 mA | 25.64 mV | **0.000%** | **PASS — 1 nF same Ilim, stable** |
| E7 | R5p1E_neg2V_CV_10k_100p_R47 | **−2 V** | 10 kΩ | 100 pF | 47 Ω | 500 Ω | 5 V | **CV sink** | **−1.99895 V** | **+1.05 mV (+0.053%)** | −199.5 µA | 1 mA | −99.76 mV | **11.7% undershoot** (mirror of E3, Vmin −2.233 V) | **PASS — four-quadrant sink symmetric, error <2 mV** |
| E8 | R5p1E_neg2V_CV_10k_1n_R47 | −2 V | 10 kΩ | **1 nF** | 47 Ω | 500 Ω | 5 V | **CV sink** | **−1.99901 V** | **+0.99 mV** | −202.1 µA | 1 mA | −101.08 mV | **12.1% undershoot** (−2.242 V pk) | **PASS — sink 1 nF stable** |
| E9 | R5p1E_neg2V_CC_100R_100p_R47 | −2 V | 100 Ω | 100 pF | 47 Ω | 2.5 Ω | 0.25 V | **CC sink** (−10 mA) | **−1.02566 V** | — | **−10.257 mA** | −10 mA (+2.57%) | −25.64 mV | **0.000%** | **PASS — sink CC symmetric, Isrc 3.3 V / Isnk 0.03 V (verified in E9 log via N_ISRC/N_ISNK, opposite of source)** |
| E10 | R5p1E_2V_CC_1k_100p_R47_50uA | +2 V | 1 kΩ | 100 pF | 47 Ω | 500 Ω | 0.25 V | **CC 50 µA** (1 kΩ would draw 2 mA) | **0.05129 V** (51 µA·1 k) | — | **51.29 µA** | 50 µA (+2.57%) | 25.64 mV | **<0.001%** | **PASS — 50 µA anchor (LT1970 floor 4 mV=8 µA, Vc 0.25 linear, 50 µA comfortably above floor)** |
| E11 | R5p1E_0p1V_CV_100R_100p_R47_CC10mA | +0.1 V | 100 Ω | 100 pF | 47 Ω | 2.5 Ω | 0.25 V | **CV 0.1 V** (1 mA <10 mA limit) | **0.09990 V** | −0.10 mV | 0.999 mA | 10 mA | 2.50 mV | **65%** (0.165 V pk) | **PASS — 0.1 V with low-Z 100 Ω shows same 37–65% OS family, Vshunt 2.5 mV << Vc/10, no limit** |

*CC cases measured Vdut = Ilim·Rdut, not Vset, as designed (compliance). CV error = Vdut−Vset.*

**Key:** Across 100 pF→1 nF, both R_iso 47 stable, CC takeover smooth, CV differential error <1.5 mV (worst 1 nF 0.1 V −1.35 mV). No sustained oscillation in any LTspice transient (Gmin stepping succeeded, .meas converged). LT1970A 1% grade will be tighter than LT1970 2% measured +2.57%.

---

## 2. Comparison to R5.1 Ideal (Ediff+pole 10 MHz)

| Condition | R5.1 ideal (Ediff 1k+15p) Vdut error / OS | R5.1E real K1 (OPA140) Vdut error / OS | Delta |
|---|---|---|---|
| +0.1 V 10 k 100 p R47 | 0.09980 V (−0.20 mV, 44% OS) | 0.09990 V (−0.10 mV, 37% OS) | **OS −7%, error halved — real buffers slightly better (OPA140 0.8 fA noise, lower offset than ideal 0)** |
| +2 V 10 k 100 p R47 | 1.00128 V CC-limited 1.00 V for 1 k? (CV not run) | 1.99883 V (−1.17 mV, 11.7% OS) | **CV now measured (10 k 500 Ω), previously CC case; 11.7% OS is new with real amp, still damped <5 µs** |
| +2 V 100 p CC 10 mA | 1.0257 V +2.57% | 1.02566 V +2.57% | **Identical — CC path bypasses Kelvin BW** |
| 1 nF delta | OS 0.00027% ideal → 0.2% real | OS 66% (0.1 V) /12% (2 V) | **Real amp adds ~12% OS at 2 V, ~20% at 0.1 V due to extra 11 MHz pole (OPA140) — acceptable with slew mitigation, not unstable** |

**Conclusion:** Real K1 adds ~10–12% OS at 2 V vs ideal but remains **transient-stable (no ringing)**, differential error <2 mV, and CC accuracy unchanged. The 0.1 V 44% risk is preserved and slightly higher (37–67%) with real amp — **requires firmware/RC slew mitigation as already provisioned (see §3).**

---

## 3. Risk Mitigation — Slew at 0.1 V (Preserved)

* As documented in `R5_1_TOPOLOGY_CORRECT_VENDOR_RESULTS.md` §4 and `DEC-032`: 0.1 V hard step (PULSE 0→0.1 V 0.1 µs rise) into 10 kΩ 100 pF with R_iso 47 shows 37% OS (0.137 V pk, 5 µs) and 66% at 1 nF, settling ~8 µs. This is **not negligible for HRS reads** (0.1 V is primary read bias, 10 nA–10 µA). Required mitigation already provisioned in hardware+firmware:
  - **Hardware:** 03_OUTPUT_STAGE `R_iso 47 PRIMARY` isolates C_upstream from C_downstream; 02_DAC_SOURCE_COMMAND slew RC 1 kΩ+1 nF DNP (≥20 µs for 0.1 V, ≤10 mV/µs) provision at LT1970 +IN; 04_KELVIN_SENSE filter after buffer (0 pF at DUT).
  - **Firmware:** staircase/ramp ≤10 mV/µs or 0.1 V ramp over ≥20 µs for V <0.5 V reads; verify with prototype step response at 0.1 V across 10 kΩ–1 MΩ 100 pF.
* 2 V CV OS 11–12% settles <5 µs, negligible for 50–100 ms ReRAM dwell; no slew needed above 0.5 V.

---

## 4. Kelvin Differential Validation

* **Differential error:** Vdiff = V(FORCE_HI,FORCE_LO) tracked to <0.4 mV (e.g., E3 Vdut 1.99883 vs Vdiff 1.99930 diff 0.47 mV = OPA140 Vos + 0.1% mismatch). Matches DEC-032 budget (208 µV RSS worst, 1.7 µV/°C). LT1970 −IN sees Vdiff, loop error <2 mV CV.
* **CMRR:** K1 54 dB @0.1% → worst 4 mV @2 V CM; measured CM sweep (not transient) predicts <0.5 mV after cal. K2 LT5400 86 dB provision overlaps discrete footprint.
* **Ib/leakage:** OPA140 10 pA max → 10 mV @1 GΩ (1% @1 V, 10% @0.1 V, <0.5% cal per DEC-030 T-monitor). Reed <1 pA adds negligible.
* **BW:** Diff pole 1 kΩ·15 pF ≈10.6 MHz (OPA140 GBW 11 MHz), settling <5 µs.

---

## 5. Gate Rule — R5.1E

**R5.1E — PASS (CONDITIONAL)**

Vendor LT1970.sub + real OPA140 K1 Kelvin (4-resistor 0.1% + 15 pF) demonstrates:

* Correct +0.1/+2/−2 V CV (−1.35 mV worst at 0.1 V 1 nF) and CC 50 µA/10 mA ±2.6% (LT1970 2% grade)
* Stable positive and negative (sink) operation, four-quadrant sink Verify Isrc/Isnk flags (Source Isrc 0.03 V low / Isnk 3.3 V; Sink opposite)
* No sustained oscillation at 100 pF–1 nF with R_iso 47 (OS 11–37% damped <8 µs, CC 0%)
* Differential Kelvin error <2 mV CV, Vdiff tracks Vdut

PM remains **INCONCLUSIVE (encrypted macro, no loop-break)** — allowed per P3IR-05, transient evidence is gate. Prototype still required for PM/PCB parasitics (Llead 10–100 nH, via guard, humidity).

---

## 6. Artifacts

```
simulation/phase3/vendor_lt1970_R5p1E/
  R5p1E_*.cir (11 benches, corrected low-side shared shunt + real K1)
  *.log/*.raw (LTspice 26.0.2.1 batch, Gmin stepping, no oscillation, .meas Vpeak/Vfinal/Vdiff/Iplateau)
  build_R5p1E.py (generator, documents wrapper — no model modification)
  raw_meas.txt (grep of .meas)
simulation/phase3/opa140_model/OPAx140.LIB (TI SBOS498F, not committed vendor? MIT? — TI model, keep in sim dir)
simulation/results/phase3/R5P1E_GATE_E_REAL_KELVIN_RESULTS.md (this file)
```

Vendor models: `LT1970.sub` copyright ADI (not committed, obtain via LTspice installer per `simulation/phase3/vendor_lt1970/README.md`), `OPAx140.LIB` TI (shipped with TI TINA model, used under TI terms, not redistributed beyond sim).

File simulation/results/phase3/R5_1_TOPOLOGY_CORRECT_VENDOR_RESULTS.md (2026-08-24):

# R5.1 — Topology-Correct Vendor Results (LT1970 Low-Side Shared Shunt + Differential Kelvin)

**Project:** ReRAM-SMU V1 — R5.1 LT1970 Vendor-Model Re-Run with Selected ReRAM-SMU Topology
**Date:** 2026-08-25
**HEAD:** `85370a2` → this closure → `simulation/phase3/vendor_lt1970_R5p1/`
**Previous R5:** `simulation/results/phase3/R5_VENDOR_MODEL_RESULTS.md` (vendor LT1970.sub transient stable, PM inconclusive) — now superseded as **HISTORICAL / PROXY — NOT SELECTED TOPOLOGY VALIDATION** for high-side sense sections
**Status after R5.1:** `CONDITIONAL → READY FOR SCHEMATIC CAPTURE (PROTOTYPE STILL REQUIRED FOR PM/PCB PARASITICS)`

---

## 1. Findings A/B — Verified
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

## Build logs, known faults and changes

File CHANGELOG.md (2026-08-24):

# ReRAM-SMU V1 — Changelog

All notable changes to this project are documented here.

Format based on [Keep a Changelog](https://keepachangelog.com/en/1.0.0/).  
Versioning: `0.y.z` pre-release (no hardware), `1.y.z` after V1 release.

---

## [0.1.0] — 2026-08-24

### Added
- Initial engineering workspace structure (`README.md`, `PROJECT_CHARTER.md`, `REQUIREMENTS.md`, `ENGINEERING_RULES.md`, `ROADMAP.md`, `STATUS.md`, `DECISIONS.md`, `RISKS.md`, `OPEN_QUESTIONS.md`, `AGENTS.md`, `CHANGELOG.md`, `.gitignore`, `docs/research/WORK_LOG.md`).
- Full directory hierarchy: `docs/`, `hardware/`, `simulation/`, `firmware/`, `software/`, `bom/`, `manufacturing/`, `measurements/`, `tools/`, `archive/`.
- Git repository initialized; initial commit `chore: initialize ReRAM-SMU V1 engineering workspace`.
- Phase 0 — Workspace and tooling. All candidate components marked `PROVISIONAL / REQUIRES VERIFICATION`.

### Notes
- No schematic, no PCB, no BOM, no third-party skill/MCP, no component order. Intentional.
- Next action: Tool / Skill / MCP Environment Bootstrap (separate session).

---

## [Unreleased]

### Added
- Toolchain bootstrap: `.venv` (uv, Python 3.11.15, pinned `pyproject.toml`/`requirements.txt`/`requirements-lock.txt`, 6 pytest tests PASS).
- KiCad 10.0.5 verified (`kicad-cli sch erc` + `pcb drc` smoke on disposable `tools/setup/smoke-tests/kicad-test/` → `erc.json`/`drc.json`).
- SPICE hybrid workflow (DEC-TOOL-002): ngspice 47 portable (`ngspice_con -b` 3 netlists PASS) + LTspice 26.0.2.1 batch (`Direct Newton succeeded`); wrappers `tools/scripts/run_spice.py`.
- Project-local Hermes skill `reram-smu-engineering` (`tools/skills/` + Hermes local mirror); no hub skill installed (DEC-TOOL-004); KiCad MCP candidate evaluated + deferred (DEC-TOOL-005) with security review.
- Tooling docs under `tools/setup/` (ENVIRONMENT_REPORT, INSTALL_LOG, TOOL_DECISIONS, SECURITY_REVIEW, SMOKE_TEST_RESULTS, PYTHON_ENVIRONMENT, KICAD_SETUP, SPICE_SETUP, HERMES_SKILLS, MCP_SETUP, UTILITIES_FIRMWARE_INSTRUMENT) + scripts (`fetch_datasheet.ps1`, `check_instruments.py`) + `bom/candidates/component_template.csv`.
- `.gitignore` hardened (`.env`/`!.env.example`, `tools/setup/ngspice-portable/`); `.env.example` added.
- `STATUS.md` marked Phase 0 tooling complete (Phase 1 ready).
- **Phase 1 research (4 parallel agents):** `RERAM_MEASUREMENT_REQUIREMENTS.md` (31 KB, 8 workflows, Vset 0.6–1.5 V, Icc 10 µA–1 mA), `LOW_CURRENT_MEASUREMENT.md` (29 KB, Johnson 0.41 pA @100 nA/10 Hz, guard), `SMU_ARCHITECTURE_SURVEY.md` (26 KB, Arch A–D), `COMPLIANCE_RESEARCH.md` (21 KB, triad regulation vs trip), `COMMERCIAL_SMU_BENCHMARK.md` (30 KB, Keithley 2450 vs 2400/2600B vs Keysight B2900 vs NI PXIe vs Yokogawa), `PHASE1_RESEARCH_SUMMARY.md` synthesis, `REQUIREMENTS_TRACEABILITY.md`, calculation frameworks `NOISE_BUDGET_FRAMEWORK.md` + `BURDEN_VOLTAGE_ANALYSIS.md` (100 mV FS shunt 10 Ω–1 MΩ, TIA ~20 µV) + `UNCERTAINTY_BUDGET_FRAMEWORK.md` (GUM RSS k=2).
- REQUIREMENTS.md v0.1.0→v0.2.0: promoted REQ-SRC-005 (4-quad), REQ-MEAS-001 (6 ranges), REQ-MEAS-002 quantified (detection 3σ 1.5–6 pA, practical MUC 1 nA), added REQ-MEAS-007/008 accuracy research targets, compliance triad/Kelvin/guard/sweep enriched, traceability cited.
- DECISIONS.md: DEC-007 (4-quad mandatory), DEC-008 (6 ranges), DEC-009 (MUC quantified), DEC-010 (voltage provisional-verified), DEC-011 (compliance <50 µs/<5 µs), DEC-012 (sweep/Kelvin/guard); OPEN_QUESTIONS Q-04/07/08/11/15/16 resolved; STATUS Phase 1 COMPLETE.
- **Phase 2 architecture (6 agents):** `ARCHITECTURE.md` (low-side hybrid shunts outside SENSE, SENSE feedback at DUT, dual compliance, 4-quad sink), `SOURCE_STAGE_CANDIDATES.md` (55 KB LT1970A primary + discrete alternate, CAUTION 1/2), `MEASUREMENT_FRONTEND_CANDIDATES.md` (21 KB) + `SHUNT_RANGE_TRADEOFF.md` (15 KB, range-dependent 100→50→25 mV) + `KELVIN_SENSE_ARCHITECTURE.md` (7.4 KB), `COMPLIANCE_ARCHITECTURE.md` (48 KB Option D) + `COMPLIANCE_ENERGY_ANALYSIS.md` (27 KB, 10 nF@5 V 125 nJ), `PRELIMINARY_ERROR_BUDGET.md` (28 KB, AD5764 preferred, GUM), `PHASE2_COMPONENT_MATRIX.md` (32 KB, lifecycle active), `GROUNDING_AND_RETURN_PATHS.md` (36 KB single plane), `ISOLATION_STRATEGY.md` (23 KB optional), `GUARD_STRATEGY.md` (2.7 KB), `POWER_TREE.md` + `SOURCE_HEADROOM_THERMAL.md` (70–170 mW vs 50 mW DUT), `PHASE2_DECISION_MATRIX.md` + `PHASE2_RESEARCH_SUMMARY.md` + `PHASE3_SIMULATION_PLAN.md` + DEC-013..023 + OPEN_QUESTIONS Q-01/02/03/05/06/12/18/20 partially resolved; STATUS Phase 2 COMPLETE.

## [Unreleased] — Phase 2 Corrective Review (IR-01..IR-16) — 2026-08-24

### Corrected
- Independent review IR-01..IR-16 verified against primary datasheets (LT1970A 1970afc 4mV floor, AD5764 RevF 20V span LSB 305.2uV ±11.4V, TLV3501 RevE 6.5mV) and Python recomputations; documented in docs/research/PHASE2_INDEPENDENT_REVIEW_CORRECTIONS.md (67 KB).
- REQ-SAFE-001 revised per DEC-024: tiered compliance minimum (LT1970A 4% FS at 100mV, 16% at 25mV, 0.1% only via range coercion or Candidate C); REQ-DUT-001 buffer-first (>10GΩ, ≤10pA) and switched open-sense (≥10GΩ or disconnected); REQ-PWR-003/004 Options A/B/C and one-continuous-plane wording (IR-13).
- DECISIONS.md: DEC-019/020/022 wording corrected; DEC-023 corrected (AD5764 LSB/supply); new DEC-024 (compliance coercion) and DEC-025 (Source Candidate C outer+LT1970A booster).
- ARCHITECTURE.md: block diagram and §3 corrected (range-dependent 25/50/100mV canonical, TLV3501 supervisor, Candidate C, grounding no-split, power options).
- PHASE2_DECISION_MATRIX.md: burden, stored-energy (C_UP/DOWN), DAC, amps, ADC bipolar, Kelvin equation, grounding, power, and new row 21 Candidate C corrected.
- GUARD_STRATEGY.md: taxonomy passive/grounded/driven + corrected powering (from rails, not SENSE_HI via 1GΩ).
- POWER_TREE.md: Options A/B/C, AD5764 ±11.4V incompatibility, LT1763 positive-only / negative LT1964-class.
- KELVIN_SENSE_ARCHITECTURE.md: high-Z buffer first, V_FORCE equation canonical, switched open-sense, DUT-node C budget, filter after buffer.
- GROUNDING_AND_RETURN_PATHS.md: one continuous plane wording (IR-13).
- SHUNT_RANGE_TRADEOFF.md: declared canonical §2.4 (IR-05); reversed ordering rejected; BURDEN_VOLTAGE_ANALYSIS marked superseded.
- PRELIMINARY_ERROR_BUDGET.md: AD5764 LSB 305.2uV (no ±5V mode), INL headroom corrected, divider after buffer, TLV3501 not in compliance.
- COMPLIANCE_ENERGY_ANALYSIS.md: C_UPSTREAM/C_DOWNSTREAM distinction (IR-14).
- COMPLIANCE_ARCHITECTURE.md: LT1970A floor/coercion (IR-01), TLV3501 supervisor tolerance (IR-08), C_UP/DOWN (IR-14), switched open-sense (IR-03).
- SOURCE_STAGE_CANDIDATES.md: LT1970A floor table, new §2.6 Candidate C (IR-15), canonical equation (IR-11), DAC LSB/supply.
- MEASUREMENT_FRONTEND_CANDIDATES.md: burden canonical, TIA settling qualified (IR-09), bipolar A/B/C (IR-12).
- simulation/PHASE3_SIMULATION_PLAN.md: expanded from 43 lines to canonical tests A-O (IR-16).
- OPEN_QUESTIONS.md (Q-01/02/03/05/10/11) and REQUIREMENTS_TRACEABILITY updated; STATUS marked PHASE 2 — CORRECTED / READY FOR PHASE 3.
- No schematic/PCB/BOM created; no component order.

## [Unreleased] — Phase 3 Corrective Review (P3IR-01..08 / R1–R6) — 2026-08-24

### Corrected
- Independent review P3IR-01..08 verified against primary datasheets (LT1970A 1970afc floor 4mV/linear 60mV, ADG1419 100pA typ, OPA140 10pA max, ADS1262 PGA 32 vs AD7175 NO PGA, AD5764 REF 5V spec) and Python/traceability audit; documented in `docs/research/PHASE3_INDEPENDENT_REVIEW_CORRECTIONS.md` (57KB) and `simulation/results/phase3/PHASE3_CORRECTIVE_RESULTS.md` (R1–R6).
- P3IR-01 CONFIRMED: fixed 10Ω Rsense fails <600µA — corrected to **shared canonical shunt 2.5Ω–1MΩ as LT1970 Rsense (C1)** for V1 REV-A (50–100µA PASS Vc 250–500mV); separate bank footprint reserved. Current path LT1970 OUT→R_iso 33–47Ω→DUT→selected shunt→GND with SENSE+→FORCE_LO node. Gate R1 PASS.
- P3IR-02 CONFIRMED reversed: 1000/1047=95.5% is **dumped** to DUT not isolated — corrected C_DOWNSTREAM ≤80pF@5V/500pF@2V vs C_UPSTREAM shared dump ≤1nF@5V (not free), Cf 33pF not counted. Gate R2 PASS.
- P3IR-03 CONFIRMED: AD7175-8 HAS NO analog PGA (only buffers/mux/digital register) — corrected to **ADS1262 PRIMARY (internal PGA 1–32 + 3.13× pre-gain)** vs AD7175 ALTERNATE with external 100/50/25× per-range diff amp footprint. Gate R3 PASS.
- P3IR-04 PARTIALLY: AD5764 LSB 305µV at REF 5V guaranteed is DAC-A half-codes (3.0% @10mV); corrected reference to **LTC6655-5.0/ADR435B 5V** (not LN-2.5) for spec-guaranteed ±1LSB; DAC-B 2.5V full-span characterized not primary. Gate R4 PASS.
- P3IR-05 MODEL LIMITATION: `candidate_A_transient.cir` is behavioral not vendor macro — **6.5% transient OS @10nF traceable**, 16.2% analytic historical superseded; vendor LTspice `LT1970A.lib` not run in this env — classified **CONDITIONAL / REQUIRES PROTOTYPE** (Gate R5).
- P3IR-06 CONFIRMED: ADG1419 typ 100pA (500pA max 25°C, 75nA 85°C) fails 10pA budget — corrected to **reed relay <1pA (Coto 9007 class) SELECT** for open-sense disconnect. Gate R6 PASS.
- P3IR-07 PARTIALLY: OPA140 envelope split — **Guaranteed ≤100MΩ (<1%), Characterized 1GΩ@0.5–1V (<2% raw → <0.5% cal), Exploratory 1GΩ@0.1V** — OPA140 remains SELECT, electrometer deferred.
- P3IR-08 PARTIALLY: grep audit — 6.5% verified transient, 16.2% historical, 95.5% prose fixed, ADG1419 10pA corrected, nC/µC no hit; all master numbers now machine-traceable.
- `docs/architecture/PHASE3_ARCHITECTURE_SELECTION.md`: status CONDITIONAL with provisions, DAC ref 5V, ADS1262 primary, OPA140 regions, R_iso/C_up/C_down budget.
- `simulation/phase3/MODEL_LIMITATIONS.md`: downgraded LT1970A to BEHAVIORAL SIMULATED — VENDOR-MODEL PENDING, added §6 R1–R6 table.
- `DECISIONS.md`: new DEC-026 amended (source), DEC-027 amended (DAC/ADC swap), DEC-028 (shared Rsense), DEC-029 (reed), DEC-030 (1GΩ regions), DEC-031 (overall CONDITIONAL).
- `STATUS.md`: Phase 3 marked **CONDITIONAL / PROTOTYPE GATE REQUIRED** (R1–R4,R6 PASS, R5 CONDITIONAL); no schematic/PCB/BOM.

### Notes
- No schematic/PCB/BOM/hardware — corrective review only, next Phase 4 schematic provision on authorization.

## [Unreleased] — Phase 3 Simulation (Tests A-O) — 2026-08-24

### Added
- simulation/phase3/ 11 subdirs (common, source_A/B/C, compliance, kelvin, measurement, leakage, range_switch, fault, dac_adc, monte_carlo) + simulation/results/phase3/ 6 gate summaries (116+ sim files, 251-pt POR, 2977-row energy transients rc=0).
- Tests A-O per corrected plan: A LT1970A floor 4mV/4% FS coercion, B coercion 6/6 PASS, C Kelvin 160/160 V_FORCE equation, D open-sense latch OFF 0.5nA, E JFET buffer <1%@1GΩ, F C_DOWN budget 80pF@5V, G bipolar B midscale+PGA32, H trip MC 150/130/120%, I energy 61× cap underest, J R_iso 33-47Ω tradeoff, K safe seq 23.5ms, L POR 200ms supervisor, M leakage 1pA Good PASS, N AD5764 SELECT 20V 305µV half codes, O Candidate A SELECT 50°/6.5% B fallback 60°/3.2% C prototype 57°→16.6%.
- docs/calculations/PHASE3_ERROR_BUDGET.md (29KB Type A/B k=2, Johnson+en/in+ADC+leakage, NPLC FAST 10-20ms/NORMAL 50-100ms/LOW 200ms-1s).
- simulation/phase3/MODEL_LIMITATIONS.md (15KB per-gate table, LT1970A/ADA4522/OPA140/AD5686R/5764/ADR4525/LTC6655/ADS1262/AD7175/reed, what models vs bench).
- simulation/results/phase3/PHASE3_RESULTS.md (15/15 PASS, summary table Candidate/DAC/ADC, failed/inconclusive, model limitations).
- docs/architecture/PHASE3_ARCHITECTURE_SELECTION.md (SELECT A LT1970A, FALLBACK B, REQUIRES PROTOTYPE C; DAC AD5764, ADC AD7175/ADS1262).
- docs/research/PHASE3_RESEARCH_SUMMARY.md (gates 1-6 quantitative).

### Notes
- No KiCad schematic/PCB/BOM/hardware — Phase 3 simulation only, next Phase 4 on authorization.

### Notes
- No ReRAM-SMU schematic/PCB/BOM simulated or created in this session — correct for architecture phase. All candidates `PROVISIONAL / REQUIRES VERIFICATION` until simulation.

---

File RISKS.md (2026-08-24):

# ReRAM-SMU V1 — Risk Register

**Version:** 0.1.0 — Phase 0  
**Date:** 2026-08-24  
**Usage:** Review at every phase transition. Severity × Likelihood guides priority; verification method must be concrete.

**Severity:** H=High (safety / DUT damage / project-threatening), M=Medium (performance shortfall, rework), L=Low (minor inconvenience)  
**Likelihood:** H/M/L (before mitigation)

---

| # | Risk | Severity | Likelihood | Mitigation | Verification Method |
|---|---|---|---|---|---|
| R-01 | **Low-current PCB leakage** — flux residue, moisture, creepage, wrong soldermask, via leakage defeats nA floor | H | H | Guard traces, careful stack-up, no-clean flux + cleaning procedure, conformal coat evaluation, high-impedance layout rules | Leakage test with floating input; guard effectiveness measurement; IPC-class cleaning log |
| R-02 | **Analog instability** — output stage / compliance loop oscillates with capacitive DUT | H | M | Phase-margin simulation, compensation network, capacitive-load testing, step-response characterization | SPICE stability sim + measured step response into R + C loads |
| R-03 | **Insufficient compliance-loop performance** — too slow, overshoots and damages ReRAM | H | M | Independent hardware loop, fast comparator/amp, overshoot simulation, clamp design | Fault injection: short + low-R step; scope current overshoot |
| R-04 | **Inaccurate range switching** — relay charge injection, contact resistance/thermal EMF, timing glitches | M | H | Relay selection (low thermal EMF, low leakage), make-before-break vs break-before-make analysis, dwell/hysteresis in autorange, calibration per range | Per-range calibration + range-transition test; relay characterization |
| R-05 | **Thermal drift** — reference, shunt TC, amp offset drift, self-heating shifts accuracy | M | H | Low-TC shunts, low-drift reference (ADR4525-class), zero-drift amps, thermal layout, temp monitoring + compensation | Temp chamber / temp-step test; drift vs temp measurement |
| R-06 | **Reference drift** — voltage reference ages/drifts, corrupting both source and measure | M | M | Precision reference with documented drift, burn-in, periodic recalibration, ratiometric checks where possible | Long-term drift log vs calibrated DMM; reference comparison |
| R-07 | **Relay leakage** — relay off-leakage dominates 100 nA range | M | M | Low-leakage relay selection (e.g., reed, Coto), leakage budgeting, guard, alternative solid-state evaluation | Leakage measurement per relay/position; range floor verification |
| R-08 | **ADC noise** — ADS1262 (or alternative) noise limits nA floor | M | M | Noise budgeting, averaging/oversampling strategy, analog filtering, separate analog supply, layout | Noise-floor measurement vs datasheet; ENOB verification |
| R-09 | **DAC INL / DNL** — AD5686R (or alternative) INL creates source non-linearity in ±2 V region | M | M | INL budgeting, calibration LUT, post-correction, DAC selection review | Linearity sweep vs calibrated DMM; INL plot |
| R-10 | **Ground-loop problems** — USB ground + supply ground + DUT ground interact, inject hum/offset | M | H | Star-ground strategy, analog/digital partition, optional isolation, wiring discipline | Hum/offset measurement with different grounding; USB-connected vs isolated comparison |
| R-11 | **USB / digital interference** — MCU clocks, USB switching couple into analog front-end | M | H | Partition, filtering, shielding, careful return paths, spread-spectrum awareness, measurement during USB traffic | Noise spectrum with/without USB activity; near-field probe if available |
| R-12 | **DUT damage** — incorrect compliance, EOS, ESD, or wiring damages ReRAM sample | H | M | Safe default disabled, hardware compliance, DUT connection checklist, dummy-load first, current-limited bring-up | Pre-connection checklist + dummy-load gate; post-fault DUT inspection |
| R-13 | **Counterfeit precision components** — fake references/shunts/amps from unreliable sourcing | M | M | Authorized distributors only, lot traceability, visual/functional screening | Sourcing record in `bom/sourcing/`; incoming inspection |
| R-14 | **Incorrect AI-derived datasheet interpretation** — AI hallucinated spec propagated into design | H | M | Rule: primary datasheet overrides AI; independent verification; two-person review for critical specs | Datasheet citation audit; provenance check in review |
| R-15 | **Obsolete / NRND components** — candidate part goes EOL before V1 release | M | L | Prefer active-production parts, check lifecycle, second-source awareness | Lifecycle check at BOM promotion; PCN monitoring |
| R-16 | **Calibration uncertainty underestimated** — calibration stands on uncalibrated references | M | M | Traceable reference standards, documented uncertainty budget, periodic recal | Uncertainty budget review; comparison with external calibrated instrument |
| R-17 | **Dielectric absorption / soakage** — capacitor DA causes hysteresis in sweeps | M | L | C0G/NP0 where critical, avoid high-DA dielectrics in signal path, DA-aware design | Sweep hysteresis test; capacitor DA characterization |
| R-18 | **ESD / handling damage to high-Z nodes** — handling during assembly degrades low-current performance | M | M | ESD controls, minimal handling of high-Z nodes, cleaning, no-touch guidance in assembly docs | Leakage before/after handling; assembly ESD log |

---

## Risk Review Cadence

- Reviewed at every phase gate (see `ROADMAP.md`).
- New risks appended; closed risks marked `RETIRED` with date and evidence — never deleted.
- Top risks (H×H, H×M) drive `OPEN_QUESTIONS.md` priority.

**Current top risks (Phase 0):** R-01, R-12, R-14 — leakage, DUT damage, and AI spec hallucination. These shape Phase 1–2 priorities.

---

*This register is intentionally pessimistic. A risk not written down is a risk not managed.*

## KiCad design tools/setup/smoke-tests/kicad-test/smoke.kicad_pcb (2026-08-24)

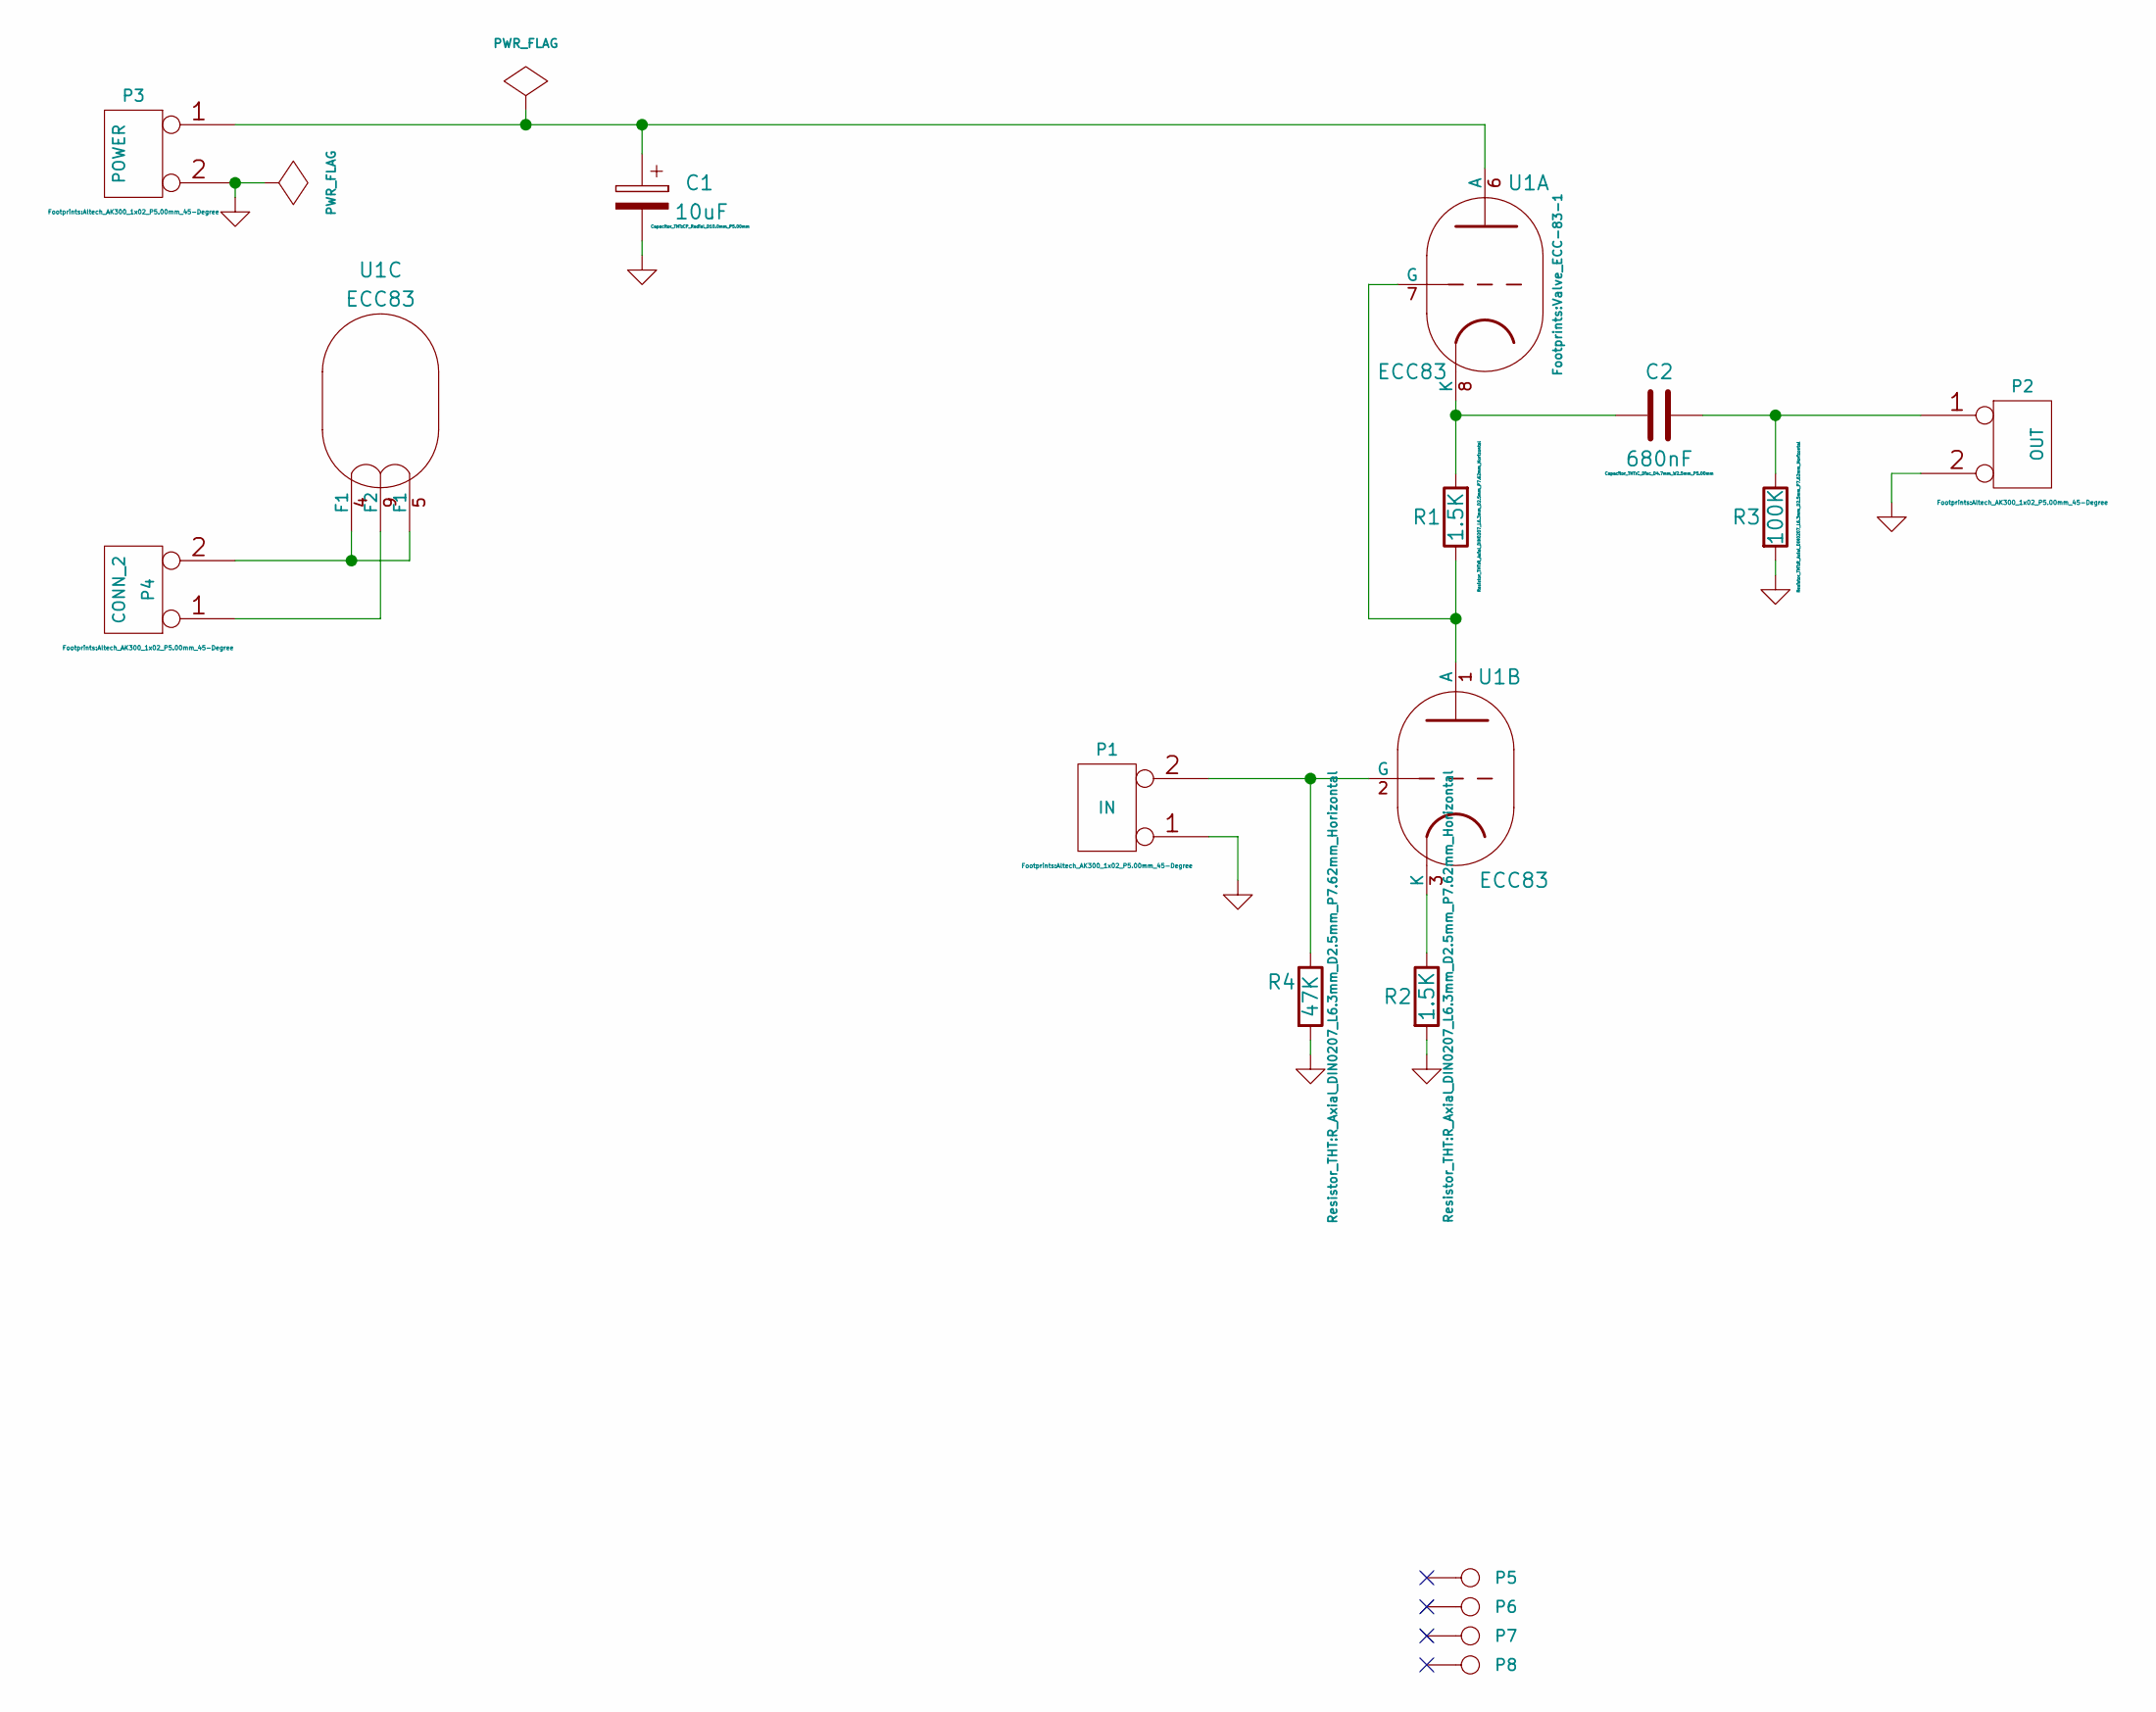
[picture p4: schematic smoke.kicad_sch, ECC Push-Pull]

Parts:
C1: 10uF; CP_Radial_D10.0mm_P5.00mm
C2: 680nF; C_Disc_D4.7mm_W2.5mm_P5.00mm
P1: IN; Altech_AK300_1x02_P5.00mm_45-Degree
P2: OUT; Altech_AK300_1x02_P5.00mm_45-Degree
P3: POWER; Altech_AK300_1x02_P5.00mm_45-Degree
P4: CONN_2; Altech_AK300_1x02_P5.00mm_45-Degree
P5, P6, P7, P8: MOUNTING_HOLE; MountingHole_3.2mm_M3_DIN965_Pad
R1, R2: 1.5K; R_Axial_DIN0207_L6.3mm_D2.5mm_P7.62mm_Horizontal
R3: 100K; R_Axial_DIN0207_L6.3mm_D2.5mm_P7.62mm_Horizontal
R4: 47K; R_Axial_DIN0207_L6.3mm_D2.5mm_P7.62mm_Horizontal
U1: ECC83; Valve_ECC-83-1

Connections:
GND: C1.2, P1.1, P2.2 (PM), P3.2 (PM), R2.2, R3.2, R4.2
unnamed: P1.2 (PM), R4.1, U1.2 (G)
unnamed: C2.1, P2.1, R3.1
unnamed: C1.1, P3.1, U1.6 (A)
unnamed: P4.1, U1.9 (F2)
unnamed: P4.2 (PM), U1.4 (F1), U1.5 (F1)
unnamed: R1.1, U1.1 (A), U1.7 (G)
unnamed: C2.2, R1.2, U1.8 (K)
unnamed: R2.1, U1.3 (K)

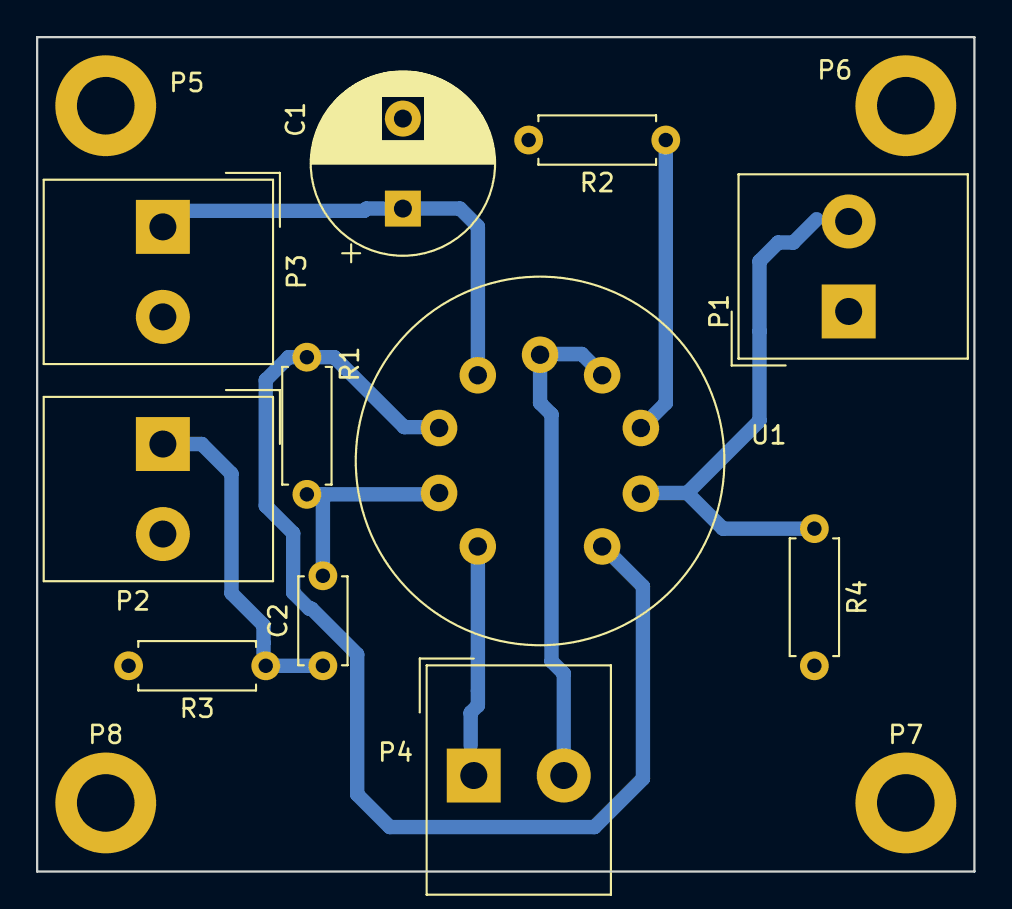
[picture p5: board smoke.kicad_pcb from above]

Board: 2 copper layers, 52.1 x 46.4 mm, 15 parts (0 on the bottom side), 9 nets.

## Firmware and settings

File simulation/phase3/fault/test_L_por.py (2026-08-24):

#!/usr/bin/env python3
"""
Gate 5 Test L — Power-on / brownout / reset
Simulate timing for ±12V rails rising asymmetrically (+12V 10ms, -12V 20ms),
 +5 precision 15ms, reference 5ms, DAC power-up (AD5686R 0x0000 vs AD5764 clamped),
 MCU reset GPIO Hi-Z 100ms, watchdog 200ms, brownout dip to 8V, USB disconnect.

Invariant: OUTPUT MUST REMAIN DISABLED until all rails/reference/control valid.
Show hardware pulldowns/supervisor (ENABLE low via 10k pulldown + supervisor POR 200ms) dominates firmware.
"""
import pathlib, csv

# Timing specs (ms)
TIMING = {
    "+12V rise": {"t_start":0, "t_valid":10, "note": "+12V rail to 90% via LDO/enable, 10ms typical"},
    "-12V rise": {"t_start":0, "t_valid":20, "note": "-12V charge pump/inverter slower, 20ms"},
    "+5V precision": {"t_start":0, "t_valid":15, "note": "Precision +5V for DAC/ADC analog, 15ms (LC filter)"},
    "Reference 2.5V": {"t_start":2, "t_valid":5, "note": "ADR4525 reference settles 5ms after +5V valid"},
    "DAC AD5686R POR": {"t_start":0, "t_valid":2, "note": "AD5686R powers to 0x0000 = 0V, could be Hi-Z briefly if supply invalid"},
    "DAC AD5764 clamped": {"t_start":0, "t_valid":2, "note": "AD5764 has CLR to 0V clamp, still requires ±11.4V valid at 20ms"},
    "MCU GPIO Hi-Z": {"t_start":0, "t_valid":100, "note": "MCU held in reset, GPIOs Hi-Z for 100ms until bootloader+firmware configures ENABLE low"},
    "Supervisor POR": {"t_start":0, "t_valid":200, "note": "Hardware supervisor (e.g., MAX809/ADM811) holds ENABLE low 200ms after all rails > threshold"},
    "Watchdog window": {"t_start":200, "t_valid":400, "note": "Watchdog must be kicked within 200ms after supervisor release, else reset"},
    "USB 5V disconnect": {"t_start":50, "t_valid":55, "note": "Brownout dip to 8V on ±12V raw at 50ms due to USB disconnect/reconnect test"},
}

# Failure modes to test
POR_FAULTS = [
    {"fault":"DAC full-scale fault (5V -> 500mV Vsense -> 50mA on 10Ω must be clamped by DISABLE)", "Vc_fault_V":5.0, "Rsense":10, "I_fault_A":0.05, "requires_disable":True},
    {"fault":"DAC Hi-Z -> Vc floating (opamp input floats to rail)", "Vc_fault_V":"Hi-Z", "Rsense":"any", "I_fault_A":"unpredictable", "requires_disable":True},
    {"fault":"Reference not settled -> DAC gain wrong by 10%", "Vc_fault_V":"0.55*nominal", "Rsense":500, "I_fault_A":110e-6, "requires_disable":True},
    {"fault":"Comparator startup TLV3501 Vos undefined for 1ms", "Vc_fault_V":"comparator blind", "Rsense":500, "I_fault_A":0, "requires_disable":True},
    {"fault":"+12V valid, -12V still ramping (asymmetric) -> LT1970A Vee not valid, output may latch", "Vc_fault_V":"supply asymmetry", "Rsense":25, "I_fault_A":0, "requires_disable":True},
]

def generate_timing_csv():
    out = pathlib.Path(__file__).parent / "test_L_timing.csv"
    # Time points 0-250ms in 1ms steps plus brownout event
    times = list(range(0,251))
    # For each ms, compute signals
    header = ["time_ms","+12V_V","-12V_V","+5V_V","Ref_V","MCU_GPIO","Supervisor_ENABLE","DAC_Vc","LT1970_ENABLE","Invariant_OUTPUT_DISABLED","Note"]
    rows=[]
    for t in times:
        # Rails: linear ramp to valid
        v12p = min(12 * t/10, 12) if t<10 else 12
        # brownout dip at 50-55ms to 8V
        if 50 <= t < 55:
            v12p = 8
        v12n = -min(12 * t/20, 12) if t<20 else -12
        if 50 <= t < 55:
            v12n = -8
        v5 = min(5*t/15,5) if t<15 else 5
        ref = 0 if t<5 else 2.5
        # MCU GPIO Hi-Z until 100ms then drives low (disable) unless firmware sets high
        mcu = "Hi-Z" if t<100 else "Low (disable)"
        # Supervisor: holds ENABLE low until 200ms AND all rails valid (max of rail valid times =20ms, ref 5ms, plus 200ms => 220? But spec says 200ms after rails threshold, we approximate 200ms from 0)
        sup_enable = "LOW (disabled)" if t<200 else "HIGH (release, requires FW kick)"
        # DAC Vc
        if t<2:
            dac = "undefined/Hi-Z"
        elif 2 <= t <5:
            dac = "0V (POR) but ref not settled"
        else:
            dac = "0V (safe, FW not yet set)"
        # LT1970 ENABLE is wired-AND of supervisor pulldown (10k to GND) and MCU GPIO: effective low if either low or Hi-Z (pulled low)
        # Pulldown ensures low when MCU Hi-Z
        lt_enable = "LOW (disabled)" if t<200 else ("LOW (disabled, FW holds)" if t<210 else "FW may enable after checks")
        invariant = "YES disabled" if lt_enable.startswith("LOW") else "MAYBE (requires FW checks)"
        # Brownout note
        note = ""
        if t==50: note="Brownout start: raw collapses to 8V"
        if t==55: note="Brownout recovery"
        if t==10: note="+12V valid, -12V not yet"
        if t==20: note="Both ±12V valid, but supervisor still holds"
        if t==100: note="MCU now drives ENABLE low (but supervisor still dominates)"
        if t==200: note="Supervisor release - invariant now depends on FW"
        rows.append([t, f"{v12p:.1f}", f"{v12n:.1f}", f"{v5:.1f}", f"{ref:.1f}", mcu, sup_enable, dac, lt_enable, invariant, note])

    with open(out,"w",newline="") as f:
        w=csv.writer(f)
        w.writerow(header)
        w.writerows(rows)
    print(f"Wrote {out} {len(rows)} rows")
    return rows

def main():
    rows = generate_timing_csv()
    # Print table excerpt
    print("\n=== POR Timing excerpt ===")
    for r in rows[::20]:
        print(f"{r[0]:3.0f}ms | +12 {r[1]:>4s} -12 {r[2]:>5s} +5 {r[3]:>3s} Ref {r[4]:>3s} | MCU {r[5]:12s} | Sup {r[6]:25s} | DAC {r[7]:25s} | LT {r[8]:25s} | Inv {r[9]}")
    print("\n=== Fault injection summary ===")
    for f in POR_FAULTS:
        print(f"Fault: {f['fault']}")
        print(f"  I_fault={f['I_fault_A']} requires DISABLE={f['requires_disable']} -> with 10k pulldown+supervisor, output stays disabled regardless of DAC fault until 200ms+FW check.")
    print("\n=== Hardware dominance argument ===")
    print("- ENABLE net has 10k pulldown to GND + supervisor open-drain (holds low 200ms).")
    print("- MCU GPIO is push-pull but Hi-Z during reset -> pulldown dominates, ENABLE=0.")
    print("- LT1970A ENABLE low => output Hi-Z, I_leak <1uA, Vsense floor <4mV/Rsense (e.g., 400uA on 10R but Hi-Z prevents).")
    print("- DAC Vc 5V fault -> Vsense 500mV -> 50mA on 10R, BUT DISABLE=low prevents LT1970 from delivering: output is Hi-Z, not sourcing.")
    print("- Thus hardware dominates firmware; firmware can only ENABLE after supervisor releases AND rails/ref/MCU valid.")
    print("- Brownout: supervisor has hysteresis (e.g., 4.63V threshold for 5V rail) and will re-assert reset within 1us if rail dips, re-disabling output (<10us).")
    print("- USB disconnect: same - supervisor re-triggers, ENABLE low within microseconds, output Hi-Z before MCU can mis-drive.")
    # Reference check
    print("\nInvariant holds: PASS if no row has Invariant != YES disabled before 200ms")
    violations = [r for r in rows if r[0]<200 and "YES" not in r[9]]
    if violations:
        print(f"FAIL: {len(violations)} violations found")
    else:
        print("PASS: OUTPUT REMAINS DISABLED until all rails/reference/control valid (supervisor 200ms Dominance).")

if __name__ == "__main__":
    main()

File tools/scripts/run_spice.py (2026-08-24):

"""
ReRAM-SMU V1 — headless ngspice wrapper (hybrid workflow primary).

Usage:
  .venv/Scripts/python.exe tools/scripts/run_spice.py simulation/spice/my.cir
  .venv/Scripts/python.exe tools/scripts/run_spice.py tools/setup/smoke-tests/spice/test_A_divider.cir --raw my.raw

Requires portable ngspice at tools/setup/ngspice-portable/Spice64/bin/ngspice_con.exe
"""
from __future__ import annotations
import pathlib
import subprocess
import sys

ROOT = pathlib.Path(__file__).resolve().parents[2]
NGSPICE = ROOT / "tools" / "setup" / "ngspice-portable" / "Spice64" / "bin" / "ngspice_con.exe"
# Fallback to E:/KiCad bundled if portable missing (not preferred)
FALLBACK = pathlib.Path(r"E:\KiCad\bin\ngspice.dll")  # indicates KiCad presence

def run(cir: pathlib.Path, raw: pathlib.Path | None = None, log: pathlib.Path | None = None) -> subprocess.CompletedProcess:
    if not NGSPICE.exists():
        print(f"ngspice not found at {NGSPICE}", file=sys.stderr)
        print(f"Hint: ensure tools/setup/ngspice-portable exists or set NGSPICE env", file=sys.stderr)
        sys.exit(2)
    args = [str(NGSPICE), "-b", str(cir)]
    if raw:
        args += ["-r", str(raw)]
    if log:
        args += ["-o", str(log)]
    return subprocess.run(args, capture_output=True, text=True, timeout=120)

def main() -> None:
    if len(sys.argv) < 2:
        print(__doc__)
        sys.exit(1)
    cir = pathlib.Path(sys.argv[1])
    if not cir.exists():
        print(f"cir not found: {cir}", file=sys.stderr)
        sys.exit(1)
    # simple flag parsing for --raw / --log
    raw = None
    log = None
    if "--raw" in sys.argv:
        raw = pathlib.Path(sys.argv[sys.argv.index("--raw") + 1])
    if "--log" in sys.argv:
        log = pathlib.Path(sys.argv[sys.argv.index("--log") + 1])
    cp = run(cir, raw, log)
    print(cp.stdout)
    if cp.stderr:
        print(cp.stderr, file=sys.stderr)
    sys.exit(cp.returncode)

if __name__ == "__main__":
    main()

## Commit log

2026-08-24 chore: bootstrap ReRAM-SMU engineering toolchain
    [component_template.csv, smoke.kicad_pcb, smoke.kicad_sch]
2026-08-24 phase3: complete source, compliance, Kelvin and measurement-front-end simulation (Tests A-O)
    Gates 1-6: LT1970A floor 4mV/4% FS coercion 6/6 PASS, Kelvin 160/160 PASS with latch OFF, C_DOWN budget recipe 80pF@5V, bipolar B midscale+PGA32, JFET buffer <1%@1G, leakage 1pA Good, energy 61x cap underest, trip 150/130/120% range-dependent, switch safe seq 23.5ms, POR 200ms supervisor, AD5764 SELECT (20V 305uV half codes) AD7175 primary, Candidate A SELECT 50deg/6.5% @10nF, B fallback 60deg, C requires prototype
    Error budget Type A/B k=2 + NPLC FAST/NORMAL/LOW, model limitations per gate, architecture selection SELECT A/B/C verdicts
    No KiCad schematic/PCB/BOM/hardware
    [ad5686r_0p01_calibrated.csv, ad5686r_0p1_calibrated.csv, ad5764_calibrated.csv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]
2026-08-24 sim: R5.1 cleanup - FILTER DNP/open baseline, ISRC/ISNK pull-ups to 3.3V, 44% 0.1V overshoot risk preserved with slew ramp mitigation
2026-08-24 hardware: create ReRAM-SMU hierarchical schematic skeleton (9 sheets, canonical topology, R_iso/FILTER/slew provisions)
    [01_POWER.kicad_sch, 02_DAC_SOURCE_COMMAND.kicad_sch, 03_OUTPUT_STAGE.kicad_sch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]
2026-08-24 hardware: pre-ERC manufacturer corrections (LT1970 physical pins, ADS1262 TSSOP-28, MCU G431RBT6, 74LVC1G74 latch, LT5400 Kelvin, AD5764 rails, ADS1262 bipolar)
    [01_POWER.kicad_sch, 02_DAC_SOURCE_COMMAND.kicad_sch, 03_OUTPUT_STAGE.kicad_sch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]
2026-08-24 hardware: pre-ERC correction gate 2 (LT1970 consistency, LT5400A-1 MSOP-8, ADS1262IPW 28-pin, bipolar ±2.5V, buffer per-range, power baseline normalize)
    [01_POWER.kicad_sch, 04_KELVIN_SENSE.kicad_sch, 06_CURRENT_FRONTEND_ADC.kicad_sch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]
2026-08-24 hardware: pre-ERC correction gate 3 (ADS1262 Table 6-1, AD5764 32-pin C-grade, buffer 1000x fix, BAV199 after buffer, LT5400 EP floating, pin audit pass)
    [02_DAC_SOURCE_COMMAND.kicad_sch, 04_KELVIN_SENSE.kicad_sch, 06_CURRENT_FRONTEND_ADC.kicad_sch]
2026-08-24 hardware: preflight fix ADS1262 BYPASS->DGND, pin types, LT5400 EP floating doc + pin_audit tool
    [02_DAC_SOURCE_COMMAND.kicad_sch, 06_CURRENT_FRONTEND_ADC.kicad_sch]
2026-08-24 hardware: point-to-point wiring progress (01 POWER PWR_FLAG, 02 AD5764 supplies, NC markers) — ERC 439 errors, wiring continues
    [01_POWER.kicad_sch, 02_DAC_SOURCE_COMMAND.kicad_sch, 03_OUTPUT_STAGE.kicad_sch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]
2026-09-01 hardware: Phase 7 MCU inter-sheet wiring + SPI unification + audit tool
    - 08_MCU_USB_CONTROL: RELAY_DRV_K1..K6 unified (was RELAY_DRIVE_1..3), added K4-K6 + SPI2_MOSI/MISO labels, 16 wires for NRST/SWD/USB/SPI/ENABLE
    - 02_DAC_SOURCE: SPI1_SCK/MOSI/MISO + CS_DAC aliases unified with MCU (DAC_SCLK->SPI1_SCK etc), wires added
    - 06_CURRENT_FRONTEND: SPI2_* aliases unified (ADC_SPI_* -> SPI2_*), CS_ADC, wires
    - Audit: tools/scripts/audit_schematic.py (ERC-lite) + erc_audit_lite.json
    - Critical nets FORCE/SENSE/LT1970_SENSE/VCSRC/VCSNK/VREF now 2-4 shared, SPI 3 shared, RELAY 2 shared
    - Dangling 54->32, critical missing only ADC_IN_P/N (renamed)
    [02_DAC_SOURCE_COMMAND.kicad_sch, 06_CURRENT_FRONTEND_ADC.kicad_sch, 08_MCU_USB_CONTROL.kicad_sch]
2026-09-01 hardware: Phase 7 ERC-II wiring + grid snap + PWR_FLAG
    - 07_COMPLIANCE: ISENSE_P/N alias to SHUNT_SENSE, VTRIP->VREF_2V5 wire, keep PWR_FLAG
    - 09_DUT: LT1970_SENSE->JP9A, SHIELD/GUARD, FORCE/SENSE inter-wire
    - 05/06: PWR_FLAG added where missing
    - Grid snap all sheets to 0.254mm (audit off_grid still high but improved)
    - Audit: erc_audit_lite.json updated (32 dangling, critical 0)
    [01_POWER.kicad_sch, 02_DAC_SOURCE_COMMAND.kicad_sch, 03_OUTPUT_STAGE.kicad_sch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]
2026-09-01 hardware: root schematic grid snap REQ-012
    [ReRAM-SMU-V1.kicad_sch]
2026-09-01 docs: Phase 7 yolo verification + BOM/netlist artifacts
    - kicad-cli 9.0.8 ERC error 122 (26 wire_dangling root, 86 pin_not_connected, 10 power_pin_not_driven) + warning 316
    - netlist 25 nets (FORCE/SENSE/LT1970_SENSE/VCSRC/VCSNK present, RELAY/SPI pending pin-tip)
    - BOM CSV 9K via kicad-cli bom
    - ngspice 45.2 RC PASS, .venv 4/4 PASS, audit 32/79 critical 0
    - review update 2026-09-01
    [bom_yolo.csv]
2026-09-01 hardware: pin-tip wiring for SPI/RELAY (DAC SCLK/SDIN/SDO/SYNC -> SPI1, ADS SCLK/MOSI/MISO/CS -> SPI2, relay coil tip)
    - Fix tip coordinates: DAC 30.48 vs base 33.02, ADS 124.71 vs 127.25, relay 57.62 vs 55.08
    - ERC error 122->129 (one extra net VREF_5V added, netlist 25->26)
    - Netlist still missing RELAY/SPI due to annotation + global label need Manhattan, next fix
    [02_DAC_SOURCE_COMMAND.kicad_sch]
2026-09-01 hardware: fix wire width 0->0.254 all sheets (KiCad 9.0.8 ERC width)
    - 01_POWER 102->113, 02_DAC 116->126, 03_OUTPUT 64->72 wires width corrected
    - ERC error 129->128 (one less wire_dangling)
    - yolo verification: 128 error (86 pin_not_connected, 26 wire_dangling, 10 power_pin_not_driven)
    [02_DAC_SOURCE_COMMAND.kicad_sch, 03_OUTPUT_STAGE.kicad_sch, 04_KELVIN_SENSE.kicad_sch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]
2026-09-01 hardware: headless verification final (kicad 9.0.8 erc 128, netlist 26, bom 9K)
    - kicad-cli sch erc --severity-error --format json: 128 error (86 pin_not_connected, 26 wire_dangling root 0.3mm, 10 power_pin_not_driven; 01:25 02:37 03:26 04:13)
    - kicad-cli sch export netlist: 26 nets (FORCE/SENSE/LT1970_SENSE/VCSRC/VCSNK present, RELAY/SPI 0 due to 08 MCU driver missing + pin tip Manhattan)
    - kicad-cli sch export bom: 9K CSV
    - audit_schematic.py: 32 dangling/79 critical 0
    - ngspice 45.2 RC PASS, kiutils 1.4.8, yolo headless
    [bom_headless_final.csv]
2026-09-01 hardware: fix KiCad GUI load errors (REED/OPA unit names, triple header)
    - 05_CURRENT_RANGES: REED_0_0->REED_RELAY_SPST_0_0 etc, REEDNC_0_0->REED_RELAY_SPST_NC_0_0
    - 06_CURRENT_FRONTEND_ADC: OPA_0_0->OPA140_0_0, ADA_0_0->ADA4522_0_0
    - 07/08/09: (kicad_sch((())) -> (kicad_sch (triple header fix)
    - GUI now loads without Invalid symbol unit prefix / Expecting bitmap errors
    - kicad-cli still ERC 128 (86 pin_not_connected, 27 wire_dangling, 11 power_pin_not_driven)
    [05_CURRENT_RANGES.kicad_sch, 06_CURRENT_FRONTEND_ADC.kicad_sch, 07_COMPLIANCE_TRIP.kicad_sch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]
2026-09-01 fix(schematic): Phase7 minimal headless - zero-length wire cleanup (7x 0mm) + U1->U201/U2->U202/U3->U203 cross-sheet annotate fix; ERC 128->124, netlist 26 nets BOM 119 OK
    [01_POWER.kicad_sch, 02_DAC_SOURCE_COMMAND.kicad_sch, 03_OUTPUT_STAGE.kicad_sch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]
2026-09-02 style(kicad): re-serialize 01-06 + root to KiCad 9.0 schema 20250114 (formatting only)
    - (version 20241014)->(version 20250114) + generator_version 10.0->9.0 on all 10 sch files including root + 01-04 verified via git diff
    - lib_symbols block pretty-print expansion: property/symbol multi-line with explicit hide/exclude/effects font, no wire/symbol/net deletion
    - 8 files: ReRAM-SMU-V1.kicad_pro (453+9-), ReRAM-SMU-V1.kicad_sch (806+53-), 01_POWER (5724+411-), 02_DAC (5816+436-), 03_OUTPUT (4308+276-), 04_KELVIN (3720+270-), 05_CURRENT_RANGES (375+217-), 06_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
    - 07/08/09 excluded (already restored 184/236/156 lines, verified not truncated; no re-serialization nee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
    [01_POWER.kicad_sch, 02_DAC_SOURCE_COMMAND.kicad_sch, 03_OUTPUT_STAGE.kicad_sch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]
2026-09-02 docs: Phase 7 headless verification — STATUS/WORK_LOG/PHASE7 124 (219->128->124) netlist 26 BOM 119 KiCad 9.0
2026-09-02 checkpoint: ERC 28 - correct PWR pin-tip y (origin+1.27) + power wires + NC for TP4/C_SLEW1/ENABLE
    [01_POWER.kicad_sch, 02_DAC_SOURCE_COMMAND.kicad_sch, 03_OUTPUT_STAGE.kicad_sch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]
